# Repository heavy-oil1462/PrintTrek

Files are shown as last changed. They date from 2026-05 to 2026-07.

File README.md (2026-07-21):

# PrintTrek

**PrintTrek** is an open-source, highly engineered, and modular offroad adventure trailer designed to be manufactured using a custom CNC router (like the PrintNC) and basic hand tools.

The whole chassis is bolted together, not welded. That is the point: you do not need welding experience, a welder, or a shop to build one. If you can drill, bolt, and torque to a spec, you can assemble the frame at home with hand tools, and the result is a joint that does not carry the fatigue risk of a bad weld you cannot inspect.

Built to traverse rugged terrain and function as an ultimate basecamp, it is specifically designed to be the perfect companion for a mid-size pickup (like the Ford Ranger), matching its track width, wheel specs, and offroad capabilities.

## Project Goals

1. **Weld-Free Assembly:** Eliminate the barrier of entry and fatigue issues associated with welding. The entire frame is bolted together using through-bolts and heavy-duty, CNC-milled aluminum corner plates (the "double sandwich" method).
2. **Open Source & Maker-Friendly:** Provide complete, open-source CAD files and instructions so anyone with access to a CNC router (like a PrintNC) can mill the complex components themselves. Additionally, 3D printed drill guides will be provided for precise hole placement, and a simplified geometry version will be available for builders without CNC access.
3. **Extreme Durability:** Utilize hot-dip galvanized steel framing, 6082-T6 aluminum nodes, and strict galvanic corrosion protection to ensure the trailer survives decades of abuse in harsh environments.
4. **Safety & Separation of Systems:** Isolate electrical and network systems on the left side of the chassis, and the propane system entirely on the right side.
5. **Modularity:** Allow builders to customize the body panels (Dibond/plywood), electrical payload, and slide-out kitchen configuration without compromising the core structural integrity.

## Key Features

- **Tow-Vehicle Synchronization:** Matches the Ford Ranger's 6x139.7 bolt pattern and track width, allowing the use of shared spare wheels (e.g., 265/60R18 Falken Wildpeak A/T3W).
- **CNC-Optimized Design:** Heavily relies on flat-pack milled aluminum brackets, niches, and nodes that can be routed accurately at home.
- **Off-Grid Capabilities:**
  - 40L food-grade water tank centrally mounted with a 3mm aluminum skid plate.
  - Dedicated drawbar mount for a 6kg propane cylinder with built-in stone protection.
  - Recessed, milled niches for external water, gas, and power outlets.
  - Modular "Power Station" 12V box, 230V mains integration, and Teltonika 5G network integration.
- **Slide-Out Kitchen:** Accommodates a heavy-duty drawer (100-150kg slides) for a 12V compressor fridge (e.g., Dometic CFX), fed via an electrical-only energy chain. Propane stays on fixed pipes to external quick-connects for outdoor cooking.
- **ESPHome + Home Assistant Control:** An ESP32 running ESPHome (relays + sensors, MQTT) with Home Assistant as the UI — monitoring water level, battery voltage/current, and temperatures, and switching the pump, lights, and fridge directly. Battery protection (tiered load shedding), pump dry-run cutoff, and runtime watchdogs run locally on the ESP32, so the network can be down without risk. Includes a full software twin: the real firmware runs under QEMU in a container against your own broker (`docs/SIMULATION.md`).

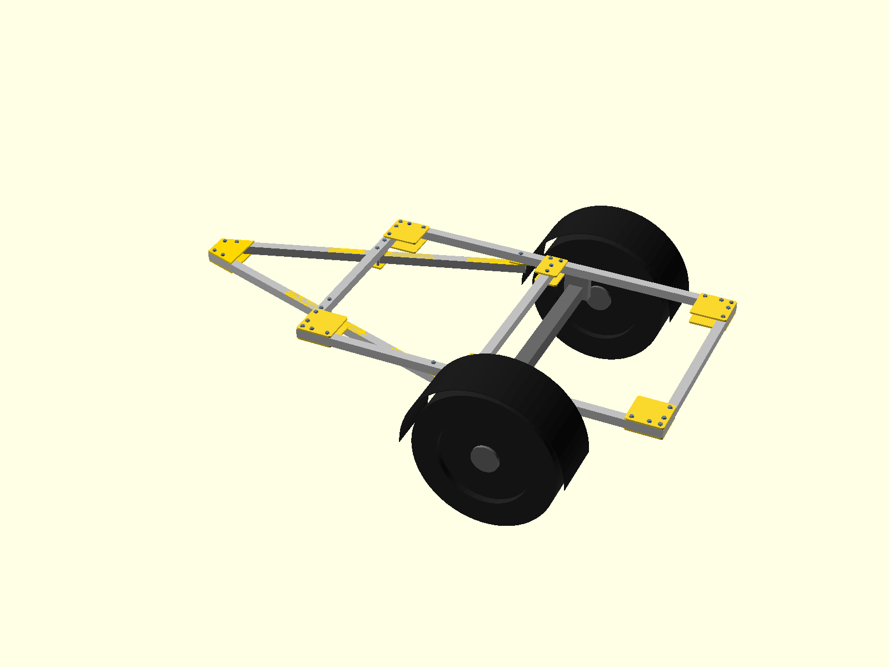
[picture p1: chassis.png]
Chassis — the load-bearing core


*The load-bearing core (what the project stands or falls on): 2000×1200 mm bolted VKR 50×50×3 frame with CNC-milled corner/T-plates, a **V-drawbar** of two straight square-cut arms in the SAME 50×50×3 profile — tied at the apex by a flat CNC plate sandwich (no welds, no miter cuts), sleeve-clamped at the front crossbeam (bolts beside the arm — no holes in it), through-bolted at the rail ends — and a braked torsion axle matching the Ford Ranger's 1560 mm track. Lateral towing loads go AXIAL through the triangle instead of bending a single beam (combined-case SF 3.0 vs 1.8). Sizing math lives in `scripts/beam_check.py` + `fea/`. Everything else (body, galley, systems) is ideation-stage layout on top of this chassis.*

## Structural Analysis

Hand-calcs (`python3 scripts/beam_check.py`) + CalculiX FEA, both validated against each other. Rebuild every derived artifact (FEA decks + solve + all renders + mass budget) on any machine with `scripts/regen_all.sh`, and gate commits with `scripts/verify_design.sh` (read-only: renders, deck drift, budget flags, FEA safety factors). FEA alone: `scripts/run_fea.sh` (needs `ccx`; renders need `pip install numpy matplotlib`). Materials: S355 steel for all VKR beams, 6082-T6 aluminum for all CNC-milled plates.

| | |
|---|---|
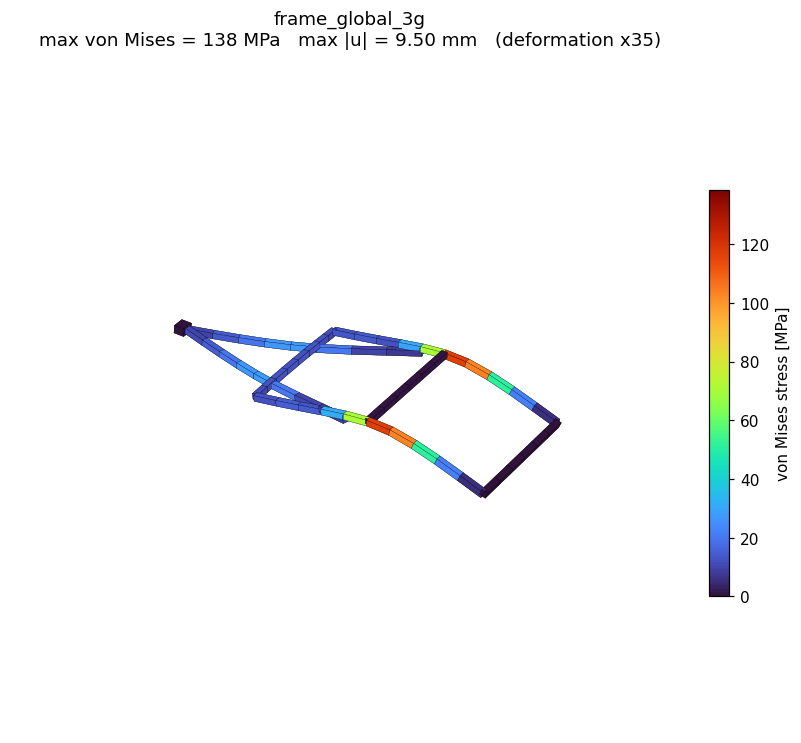
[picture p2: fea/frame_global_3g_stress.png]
Whole chassis, 3g
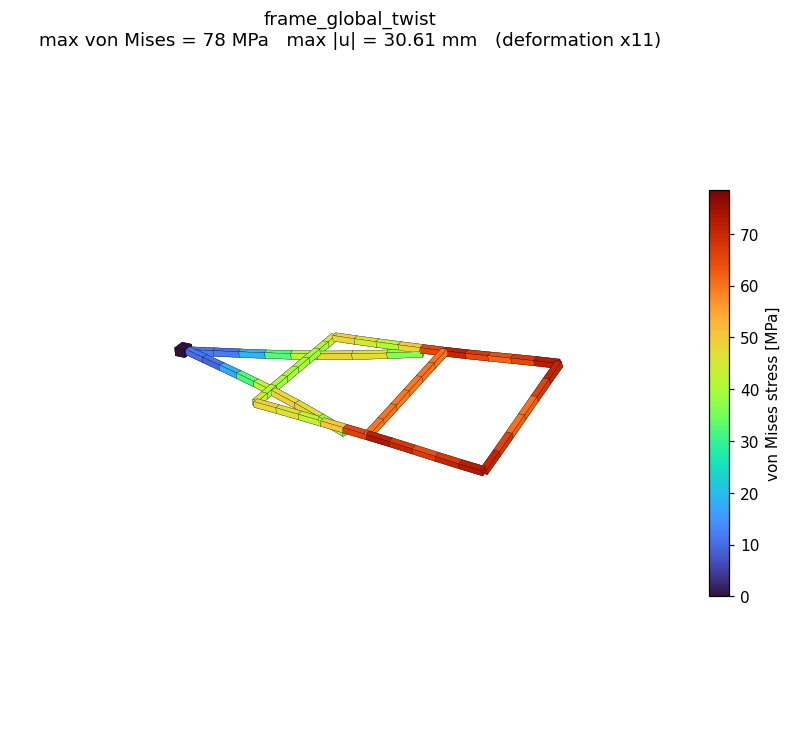
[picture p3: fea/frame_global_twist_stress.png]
Whole chassis, racking
|  |  |
| **Whole chassis, 3g deck load** — rails 130 / crossbeams 16 / V-arms 31 MPa, **SF ≥ 2.7 on every member** (bounding: full 400 kg at 3g); bolted laps appear as connectors (28 MPa — bolt preload/friction budget in `check_v_joints`) | **Whole chassis, diagonal racking** (one corner lifted 30 mm) — 74/70 MPa; the bolted ladder frame is torsionally soft, which is what you want off-road |
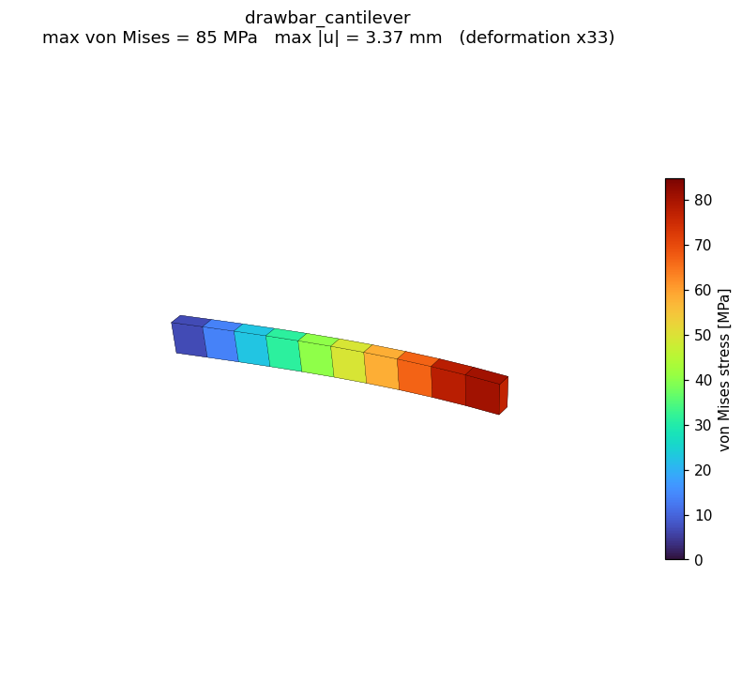
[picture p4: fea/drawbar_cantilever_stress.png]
Drawbar FEA
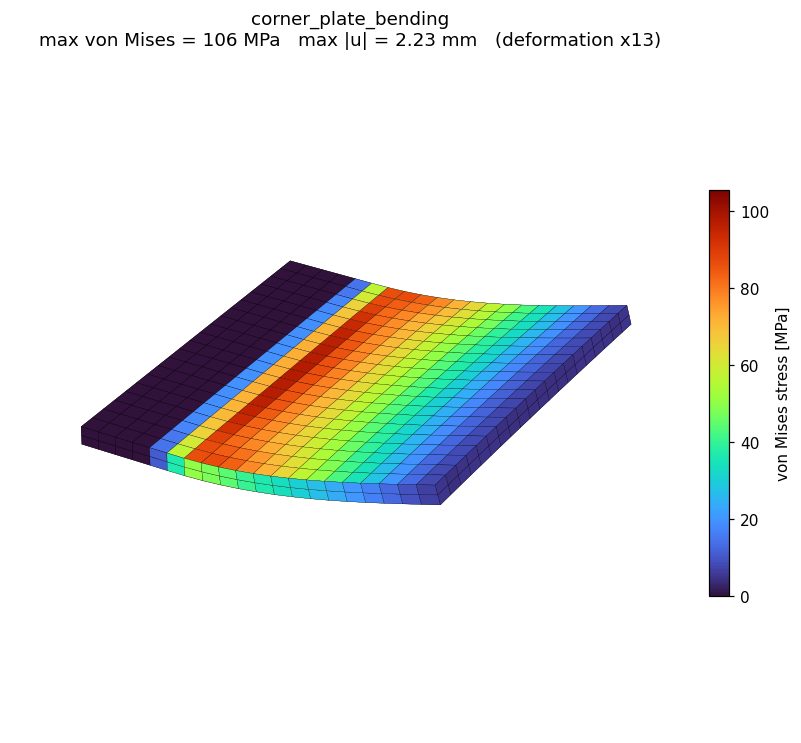
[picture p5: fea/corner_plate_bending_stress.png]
Corner plate FEA
|  |  |
| **Single-bar drawbar** (legacy variant, kept as solver validation): 85 MPa at the root, SF ≈ 4 — matches the hand calc | **Corner plate** (aluminum, prying bound): 106 MPa at the clamp line, SF ≈ 2.5 even with one plate taking the full couple |

The fatigue-governing detail of any bolted drawbar is a bolt hole at the peak-moment point (`check_joint_hole` / `check_v_joints` in `beam_check.py`), so the rule everywhere is **no holes where bending peaks**: at the front-crossbeam crossing the V-arms are CLAMPED — two bolts pass through the crossbeam *beside* the arm, through spacer sleeves, pulling a plate up under it — and through-bolted only at the rail ends and apex plates, where arm moment is ~zero. Every structural bolt runs at full preload on a crush sleeve, so service loads are carried by **friction grip** (SF ≥ 3.9, `check_v_joints`) — the bolts never work in shear and the holes stay clamped shut. Per-member tables and model notes in [`fea/README.md`](fea/README.md).

## Design Snapshots (ideation-stage layout)

| | |
|---|---|
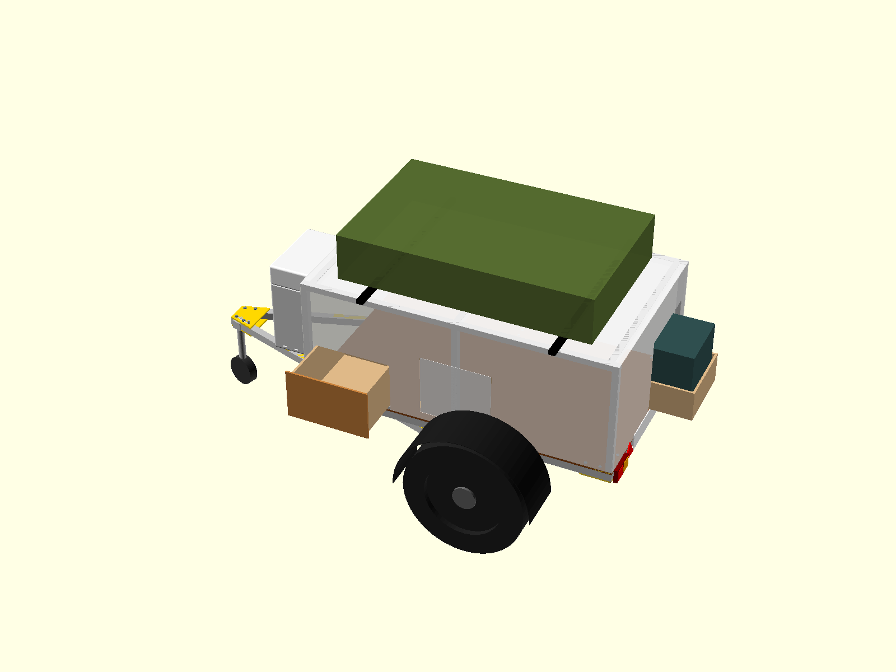
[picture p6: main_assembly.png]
Main assembly
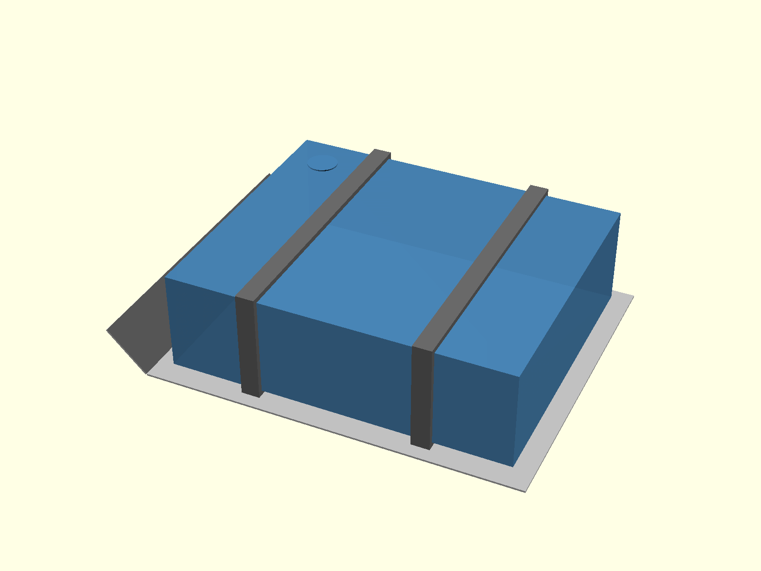
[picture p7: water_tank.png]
Water tank + skid plate
|  |  |
| **Full assembly concept** — kitchen side-drawer front left, storage cabinet mid left, electrical bay mid right, fridge drawer out the rear right | **Low-profile 40 L water tank** — 160 mm deep so the 3 mm skid plate sits level with the axle tube (~405 mm clearance); mounting under review, currently not in the assembly |

The body/galley layout is still being iterated and does not drive the structure. Renders are generated headlessly with `scripts/render_scad.sh cad/<model>.scad <output>.png` (chassis-only: add `-D show_cabin=false -D show_equipment=false`).

## Control System (ESPHome + Home Assistant)

The trailer is controlled by an ESP32 running [ESPHome](https://esphome.io) with Home Assistant as the UI. Everything below needs the toolchain on PATH — `pip install -r requirements.txt` (plus the mosquitto system package) or the pinned dev shell (`nix develop`), whichever you prefer:

```bash
python3 tools/stack.py init && python3 tools/stack.py up   # dev stack: mosquitto + HA
python3 tools/mock_device.py --discovery                   # software twin, no hardware
esphome run esphome/example-trailer.yaml                   # real hardware (copy + edit first)
```

Or run the REAL firmware without hardware — an esp32 build under Espressif QEMU in a container, against your own broker and HA, with a web panel to inject sensor values (`docs/SIMULATION.md`):

```bash
python3 tools/sim_container.py build
python3 tools/sim_container.py run --broker <mqtt-host> --username u --password p
```

The node is live on the network by default (direct switch control from HA); a duty-cycled storage mode with retained setpoints is one switch away. Safety logic — tiered battery load shedding, pump dry-run cutoff, runtime watchdogs — runs locally on the ESP32 regardless of connectivity. The MQTT contract is in [`docs/PROTOCOL.md`](docs/PROTOCOL.md); adopt/extend via composable packages per [`docs/EXTENDING.md`](docs/EXTENDING.md); controller wiring in [`docs/HARDWARE.md`](docs/HARDWARE.md).

## Toolchain and CI

Nix is optional everywhere. The software gate needs python3 plus esphome, yamllint and the esphome_skills package (`pip install -r requirements.txt` or `nix develop`); the CAD pipeline needs a 2024+ OpenSCAD dev snapshot, resolved as `$OPENSCAD`, then `openscad` on PATH, then nix; CalculiX resolves the same way (`$CCX`, PATH, nix). The pre-commit gate is `scripts/verify_design.sh`, and CI (`.github/workflows/`) runs exactly the same gates from pip with no nix: `validate.yml` (configs + MQTT protocol test) on every change, `design.yml` (CAD renders, FEA drift and safety factors, mass budget) on design-side paths, `firmware.yml` (full C++ build of both node configs) on firmware paths.

## Repository Structure

- `/cad`: Contains all the 3D models and manufacturing files (e.g., OpenSCAD, STEP, or STL files) for the corner plates, niches, and chassis geometry.
- `/concepts`: Markdown files and diagrams detailing sub-systems (like electrical routing, propane layout, and water flow).
- `/esphome`: The trailer control firmware — a composable ESPHome base + packages (sensors, actuators, load shedding); see `docs/EXTENDING.md`.
- `/homeassistant`: Home Assistant package (derived sensors, alerts), alert blueprint, and an example dashboard.
- `/server`: Dev/test stack (mosquitto + Home Assistant via docker compose). The production stack will run nix-managed on the trailer's Raspberry Pi.
- `/sim` and `/tools`: The firmware simulator (real esp32 build under QEMU + web control panel), mock device, protocol test, and the validation gate (`tools/validate.py`).
- `/docs`: Control-system contracts — `PROTOCOL.md`, `EXTENDING.md`, `HARDWARE.md`, `SIMULATION.md`.
- `/scripts`: Helper tools — `calculate_tubes.py` (steel cut list from the CAD files) and `calculate_mass.py` (weight, center of gravity, and tongue-load budget).
- `MATERIALS.md`: A comprehensive Bill of Materials (BOM) detailing the steel, aluminum, fasteners, and specific off-the-shelf components required.
- `SPECS.md`: The core technical specifications and overarching design decisions.
- `TODO.md`: The phased checklist of design, purchasing, and construction tasks.

## How to Contribute or Build Your Own

Currently, the project is in the **Concept & CAD Design phase**. 

If you are interested in building your own PrintTrek, or want to contribute to the CAD models, electrical schematics, or documentation, feel free to fork this repository, open an issue, or submit a pull request!

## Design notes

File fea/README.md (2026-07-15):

# FEA — CalculiX models

Finite-element checks for cases where the hand-calcs in
`scripts/beam_check.py` aren't enough (joint details, plate bending,
combined load paths). Solver: **CalculiX (ccx)**, open source.

## Run it (any host)

```bash
scripts/regen_all.sh        # EVERYTHING: decks + solve + all PNGs + mass budget
scripts/verify_design.sh    # read-only checks incl. FEA SF >= 1.5 (pre-commit)
scripts/run_fea.sh          # just this: solves every fea/*.inp + renders PNGs
```

The script finds `ccx` via `$CCX` → PATH → nix-build fallback
(Debian/Ubuntu: `apt install calculix-ccx`). Renders need
`python3` with numpy + matplotlib (`pip install numpy matplotlib`);
without them the solve still runs and the script prints a hint.
Single deck: `scripts/run_ccx.sh fea/<deck>` (no `.inp` extension).
Render manually: `python3 scripts/plot_fea.py fea/*.frd`.

## Materials (configured per part, units mm/N/MPa)

| Material | Used for | E [MPa] | ν | Yield [MPa] |
|---|---|---|---|---|
| **S355J2H steel** (`*MATERIAL, NAME=S355`) | VKR beams: frame, drawbar, crossbeams | 210 000 | 0.30 | 355 |
| **6082-T6 aluminum** (`*MATERIAL, NAME=AL6082T6`) | CNC-milled plates: corner, T, spacer, cradle | 70 000 | 0.33 | 260 |

## Conventions
- Beam models use `B32R` elements (`SECTION=BOX` requires the reduced-
  integration type in ccx); solid plate models use `C3D8I` (good in bending).
- Every deck header states the load case and the expected hand-calc result —
  a model that can't be sanity-checked is worse than no model.
- Only `.inp` decks and `_stress.png` renders are versioned; `.dat`/`.frd`
  solver output is disposable (gitignored).

## Models

### drawbar_cantilever.inp — steel, VALIDATED ✔
Single-bar drawbar LC1 (legacy variant — kept as the beam-model solver
validation): VKR 100x50x4 standing, 1090 mm cantilever, 3g × 80 kg = 2354 N
tip load.

| Quantity | Hand calc | ccx |
|---|---|---|
| Tip deflection | 3.36 mm | 3.36 mm |
| Root bending stress | 89.0 MPa | 84.7 MPa* |

Drawbar stress

### corner_plate_bending.inp — aluminum, VALIDATED ✔
Corner plate prying bound: 200×200×10 mm 6082-T6 plate, clamped strip over
the tube face, 2.5 kN transverse at the free edge (≈ drawbar-lap couple).
Conservative: one plate takes what the top+bottom sandwich pair shares.

| Quantity | Hand calc | ccx |
|---|---|---|
| Edge deflection | 2.15 mm (plate-stiffened) | 2.23 mm |
| Clamp-line stress | 113 MPa | 105.5 MPa* |

SF vs 6082-T6 yield (260 MPa): **~2.5** even in this bounding case.

Corner plate stress

\* ccx reports stress at integration points slightly inside the extreme
fiber / clamp line — reading a few % below the hand-calc envelope is
expected; use the hand calc as the conservative number.

### frame_global_3g.inp + frame_global_twist.inp — WHOLE CHASSIS
The entire load-bearing structure in one beam model: rails, three
crossbeams (front, mid at x 950-1000, rear — no beam over the axle, the
bolted axle tube ties the rails there), and the **V-drawbar** (default,
`v_drawbar` in `cad/design_params.scad`): two straight 50×50×3 arms
35 mm below the frame plane, sharing the apex node (= the apex-plate
sandwich), a stiff APEX connector out to the coupling, and short
vertical VJOINT connectors for the bolted laps at the front-crossbeam
crossings and the rail ends. The legacy single-bar variant remains
generated by `v_drawbar=false`. Vertical supports sit on the RAILS at
the axle brackets (x≈1100). Generated parametrically:
`python3 scripts/gen_frame_fea.py`.

**LC 3g vertical** (400 kg deck × 3g, supported at coupling + axle
brackets) — max von Mises per member group:

| Member group | max vM | SF vs 355 |
|---|---|---|
| Side rails | 130 MPa | 2.7 |
| Crossbeams | 16 MPa | 22 |
| V arms (DRAWBAR) | 31 MPa | 11* |
| Lap connectors (VJOINT) | 28 MPa | 13 — bolt-level check: `check_v_joints` |

\* the isolated 3g-tongue case (164 MPa/arm, SF 2.2, `check_v_drawbar`)
remains the arms' governing envelope — dynamic pitching loads the
tongue independently of the deck. The rails govern the frame in this
bounding case (full 400 kg payload at 3g), same as before: the V
actually RELAXES the front crossbeam (27 → 16 MPa) because the coupling
reaction enters at two crossing points instead of mid-span. The two
OPTIONAL floor crossbars (x=500/1500, `floor_crossbars` toggle, OFF by
default) change frame-member stresses by ~nothing — verified here —
their job is the formply floor span, lashing points, and the water-tank
hanger, not the frame.

**LC diagonal racking** (three corners held, fourth lifted 30 mm): rails
74 / crossbeams 70 / V arms 56 MPa; the lap connectors read 60 MPa
(load-path indicators for the bolted joints). The open ladder frame is
torsionally soft — good off-road, and stresses stay low. (A "one
wheel up" case with a ball coupling is a near-rigid roll of the whole
trailer — verified zero stress — because the ball transmits no roll
moment.)

Global 3g
Global racking

**Joint modeling honesty:** member intersections are rigid shared nodes
and the laps are stiff links — **bolts are not modeled discretely** (no
preload, no contact, no friction in these decks). That idealization is
fair as long as every joint stays in friction grip, which is exactly
what `check_v_joints` in `scripts/beam_check.py` verifies (M12 8.8 at
full 47 kN preload, μ=0.2 slip capacity vs joint demands, SF ≥ 3.9).
Bolt shear/bearing and net-section fatigue live there too; a true
preload+contact model of one bolted joint is still open work.

## Next candidates for FEA (when the design firms up)
- **Drawbar cradle joint** (`cad/drawbar_cradle.scad`): preload+contact
  model of cradle + beam + crossbeam confirming the no-hole-in-flange
  concept — see `check_joint_hole` in `scripts/beam_check.py`.
- Local wall bending of the 4 mm RHS around the crush sleeves under the
  lateral couple.
- Semi-rigid joint stiffness in the global model (springs calibrated from
  a single-joint contact model) instead of rigid shared nodes.

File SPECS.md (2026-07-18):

# Technical Specifications & Design Decisions

## Overall Goals
- **Tow Vehicle:** Ford Ranger
- **Track Width and Bolt Pattern:** Matched exactly to the tow vehicle (6x139.7). Tire size: 265/60R18 Falken Wildpeak A/T3W on Ford original rims. The Ranger's underslung spare serves both car and trailer — no spare is carried on the trailer.
- **Manufacturing Technique:** Custom-built CNC router (PrintNC) is utilized maximally for precision, corner joints, brackets, niches, and modular panels. Additionally, 3D printed guides will be used to ensure precise drilling of holes in the steel beams. A simplified, non-CNC version with cruder geometry will also be provided for builders without access to CNC routing.

## 1. Chassis & Mechanics
- **Frame Structure:** Square steel (VKR 50x50x3 or 60x40x3 mm), frame 2000 x **1200 mm**. Crossbeams at ~500 mm spacing (x = 0 / 500 / 975 / 1500 / 2000): the mid beam ties the rails ahead of the axle (and takes the drawbar lap in the legacy single-bar variant); the two floor crossbars are **OPTIONAL** (single toggle `floor_crossbars` in `cad/design_params.scad` — ONE file read by the CAD assembly, the mass budget, and the FEA generator alike; per-run overrides via UPPERCASE env vars, e.g. `FLOOR_CROSSBARS=true scripts/regen_all.sh`) and exist for the **floor**, not the frame — they halve the formply's unsupported span under cargo point loads, provide lashing/body mounts, and the rear one is the water-tank hanger. Each end bolts to the rail through the same **top+bottom T-plate sandwich** as the mid crossbeam (same CNC part, same joint everywhere in the frame — 4 plates per bar). Cost of the pair: +22 kg incl. plates; the toggle is **OFF by default** in all three places. (FEA: frame-member stresses are unchanged by them — rails are supported by the wheels and coupling, not by crossbars.) The frame was narrowed from 1400 mm because matching the Ranger's 1560 mm track is otherwise geometrically impossible: with 265 mm tires, tire-to-body clearance is (1560-265)/2 - 600 = **47.5 mm** at 1200 mm width, but negative at 1400 mm. No full welding to prevent fatigue cracks; the frame is bolted together with through-bolts (M12 in 8.8/10.9 grade — one bolt size frame-wide, 2 per plate arm on the tube centerline).
- **Bolted Joints (critical):** Every through-bolt runs through an **internal steel crush sleeve** (precision tube, 20x3 mm for M12) so the bolt can be torqued to full preload without collapsing the 3 mm RHS walls. Lock nuts and hardened washers throughout. **Re-torque all structural bolts after the first ~500 km, then annually.**
- **Drawbar (DECIDED 2026-07-15): V-drawbar (A-frame)** of two straight, square-cut **VKR 50x50x3** arms — the same profile as the rest of the frame, so ONE tube size builds the whole trailer. The arms run from under the side rails (rear ends at x=800 — the V is kept this narrow so the crossing clamp bolts clear the 200×200 corner plates) through the front crossbeam to the coupling apex; all the V geometry lives in one flat CNC part, the **apex plate** (`cad/v_apex_plate.scad`, 10 mm 6082-T6, top+bottom sandwich over both arm ends) — **no welds, no miter cuts**, and the tips stop with a deliberate ~40 mm gap (`v_tip_gap`) so cut tolerance never lets the tubes press on each other. Why it beats the single bar (`check_v_drawbar` in `scripts/beam_check.py`): vertical 3g tongue splits over two arms (164 MPa/arm, SF 2.2); **lateral loads resolve AXIALLY through the triangle** (6 MPa, vs 135 MPa weak-axis bending + a lap couple in the single bar); the governing combined case (2g vertical + 0.3g lateral) gives **SF 3.0 vs 1.8** for the single bar — and the pair is ~5 kg lighter. Arm buckling SF ~100. Attachment: **front-crossbeam crossing = SLEEVE-CLAMP** — two M12 pass through the crossbeam 45 mm each side of the arm, down through 60 mm spacer sleeves into a 10 mm clamp plate under the arm, squeezing it against the wedge plate/crossbeam. **Zero holes in the arm** at its peak-moment point (the fatigue rule), and nothing lands on a beam edge — U-bolts were tried and rejected (at the ~70° skew their legs hit the crossbeam's edges). **Rail ends = ONE M12 through-bolt** each (the shallow overlap only has edge distance for one; arm moment ~zero there); **apex plates = 2x M12 per arm**; crush sleeves everywhere. The coupling-head mounting at the apex is an open design point (type-approved head required). The legacy **single central VKR 100x50x4** remains fully modeled (CAD, mass, FEA) behind `v_drawbar=false` in `cad/design_params.scad`. There is still **no separate crossbeam over the axle**: the bolted axle tube ties the rails via its brackets; the mid crossbeam is now purely a rail tie.
- **Drawbar joint rule — NO HOLES AT THE PEAK-MOMENT POINT.** The governing detail of any bolted drawbar is never the beam, it's a bolt hole through a tension flange where bending peaks (net section −17%, kt ≈ 2.5, fatigue margin collapses — `check_joint_hole`). In the **V-drawbar (default)** this is why the front-crossbeam crossing is the **beside-the-arm sleeve-clamp** and through-bolts appear only at the rail ends and apex plates where arm moment is ~zero (`check_v_joints`: with holes at the crossing the 2g fatigue range fails, 139 MPa vs category 90; clamped it passes with 1.45× margin). For the **legacy single bar** the same rule produced the front-crossbeam clamp — vertical bolts *beside* the beam, horizontal M12 through the webs at the **neutral axis**. Three interchangeable single-bar implementations, same structural concept:
  1. **Angle-bracket pair** (was the decided single-bar joint): 2x hot-rolled **L80x80x8** S355, 120 mm long, straight cuts only, galvanized with the frame (`cad/drawbar_angle_joint.scad`). Leg-bending SF ≈ 3.4 with the pair coupled by the through-bolts (`check_angle_joint` in `beam_check.py`); 6 mm legs drop to SF 1.9 — use 8 mm. The 10 mm spacer plate stays.
  2. **CNC-milled 6082-T6 cradle** (`cad/drawbar_cradle.scad`): one-piece channel + wings, integrated spacer web — the premium/CNC variant.
  3. **Square U-bolts** (fyrkantbygel M12 for 50 mm profile) + top plate: fully off-the-shelf trailer hardware; add a saddle strip so the U-bend doesn't dent the tube corners. (Note: U-bolts do NOT work for the V-drawbar's crossings — at the ~70° skew their legs land on the crossbeam's edges — which is why the V uses the sleeve-clamp instead.) The coupling itself must be a type-approved unit with a documented rating.
- **Corner Reinforcements:** "Double sandwich" with heavy-duty, CNC-milled 8-10 mm aluminum plates (6082-T6) on the top and bottom of each 90-degree corner.
- **Surface Treatment:** The steel frame is hot-dip galvanized after drilling. Holes are drilled 13 mm (M12) and **reamed clean after galvanizing** — hot-dip adds ~100 µm of zinc per surface.
- **Corrosion Protection:** Duralac (anodic paste) on all steel–aluminum interfaces; optionally a thin *rigid* isolator sheet (0.5-1 mm G10/FR4). **No rubber or vinyl inside structural joints** — elastomers creep under sustained compression and destroy bolt preload, which is the exact loosening/fatigue failure mode the bolted design must avoid. Note that galvanized steel against aluminum is a relatively benign pairing (zinc is anodic to aluminum), so paste + galvanizing is sufficient protection.
- **Suspension:** Torsion (rubber) axles have limited travel (~70 mm) and no damping — on washboard/corrugated roads they overheat and pound the payload. Specify **shock absorbers (damper kit)** with the torsion axle as a minimum; evaluate axle-less trailing-arm setups (e.g., Timbren) if serious off-road use is intended.

## 2. Electrical System & Electronics (LEFT Side)
- **Placement (sides in TRAVEL direction):** All electrical is concentrated on the **right side**: the electrical bay (removable power-station box, IP65 cabinet, el-niche with router panel) sits mid-right, directly **ahead of the fridge drawer** (rear right). The 230V CEE inlet sits on the front wall's right half, mounted high — a short, clean feed down into the right-side bay. **NOTE:** the old strict gas-left/electric-right separation principle is *parked* while the interior layout settles (decision 2026-07-08: layout first, then refine gas routing/placement around it).
- **Cable Routing:** Cables in corrugated conduits inside the steel frame. The conduits exit the steel before the corners and are routed in a soft curve protected within the tunnel between the corner plates.
- **Grounding:** Single-Point Grounding (Star grounding). The steel frame is equipotentially bonded with a 6 mm² yellow/green cable to a grounding terminal in an IP65 electrical cabinet.
- **230V Network:** Blue CEE inlet -> Fuse box (RCD + 10A/13A circuit breakers) -> Outlets (fridge, Noco charger, IP66 external).
- **12V & Battery Module:** Detachable Power Station box with a **200 Ah LiFePO4** bank, DC-DC MPPT charger, Noco charger, and Anderson connectors. Charged from the car's 13-pin socket while driving and from a **200 W solar panel** on the roof rack (MC4 via the external solar input).
- **Energy Budget (12V):** Maintained in `scripts/calculate_energy.py` — edit the load table there and re-run as components are chosen. Current estimates: ~64 Ah/day total (compressor fridge ~34, router/RPi/lights/pump ~30). Autonomy with 200 Ah + 200 W solar: **~32 days parked in summer sun, ~5 days in shade/shoulder season, ~3.4 days overcast**; one day's consumption is recovered by ~2 h of driving (30 A DC-DC). The comparison in the script also shows why the gas absorption fridge was rejected: without solar even *it* is battery-limited to ~3 days by the base loads, so solar is required either way — and a compressor fridge with solar then beats gas on every axis (works off-level, no flame under the roof tent, no flue, slide-out compatible).
- **Network:** Teltonika 5G industrial router, coaxial LMR-200/400 to Poynting puck antenna. Waterproof N-connectors in a CNC-milled, recessed panel.
- **Monitoring & Control:** An ESP32 running ESPHome (in the electrical bay) switches the pump, exterior lights, and fridge relay and reads battery voltage/current (INA226 + shunt), tank level, interior climate, and fridge temperature over MQTT into **Home Assistant** — direct control from HA, with the safety logic local on the ESP32 (tiered battery load shedding, pump dry-run cutoff, runtime watchdogs; `docs/PROTOCOL.md`). The on-trailer server is a Raspberry Pi; the dev stack lives in `server/`, the production Pi will run a nix-managed HA/Grafana/Loki/Prometheus stack (separate config, not in this repo yet).

## 3. Propane System (RIGHT Side)
- **Separation:** All propane on the right side for complete isolation from the electrical system.
- **Bottle housing:** 6 kg (P6/PK6) in a **caravan-style gas locker box** on the drawbar, flush against the front wall (`cad/gas_box.scad`). Lockable and weatherproof (stone protection all around, not just a front guard), with **low-level vent slots per EN 1949** (propane sinks) and the regulator/hose inside; the fixed pipe exits a floor gland to the right-side rail. Available off the shelf (poly drawbar boxes, Fiamma/Thule class) or CNC-folded in aluminum tread plate. Mounted on bearers **clamped** around the drawbar — the forward beam carries near-peak bending moment, so no holes in it. (The open CNC cradle + stone guard remains as the budget alternative, `cad/gas_bottle_mount.scad`.)
- **Routing:** Fixed, clamped copper or steel pipes under the right frame. Bulkhead fittings at consumers.
- **External Outlets:** Two fixed gas quick connects (GOK/Truma) in CNC-milled protective niches on the **right wall**: one **front-right** (short hose around the front to the slide-out kitchen counter on the front left) and one **rear-right** (griddle/outdoor kitchen at the tail). Mounted low-ish — propane is heavier than air, so the connects stay below the 230V inlet and away from any opening into the cabin — but above wheel-spray height.

## 4. Water System & Interior
- **Water Tank (mounting UNDER REVIEW):** 40-liter **low-profile** tank (550x450x160, food-grade with baffles), modeled in `cad/water_tank.scad` but currently removed from the main assembly — the underslung mounting is being reworked. Candidate spot: **behind the axle, centered** (x≈1400) — freed up now that no spare wheel is carried; there is no drawbar under the floor there (the beam ends at x=1020) and it balances the gas box up front. Caveat: with water behind the axle, the tongue load *rises* as the tank drains (see the dry-tank line in `calculate_mass.py`). Shallow on purpose: at 160 mm depth the skid plate sits ~405 mm above ground, level with the axle tube, instead of being the trailer's lowest point. Protected by a 3 mm aluminum tread skid plate with a beveled leading edge. Mass is kept as a placeholder in the tongue budget.
- **Water Components:** External lockable filler (in Dibond wall), 12V pressure-controlled galley pump (Seaflo/Shurflo), central drain valve.
- **Body:** Floor in 12-15 mm vehicle plywood (formply). Sides in 3-4 mm Dibond on steel/aluminum framework.
- **Galley & Bay Layout (sides in TRAVEL direction, `cad/kitchen_drawer.scad`):**
  - **LEFT, front → rear:** kitchen side-drawer, then storage cabinet.
    1. **Kitchen side-drawer (front left):** 520 x 680 mm drawer on 100-150 kg lock-in/out slides, pulling out *sideways* through an opening in the left wall — worktop over the rear half, open bins in front. Structural slides only in CAD; taps/stove are loose equipment.
    2. **Storage cabinet (mid left):** Fixed plywood cabinet (650 x 450 x 550) for utensils/dry goods, exterior door in the left wall (x 780-1240).
  - **RIGHT, front → rear:** electrical bay, then fridge drawer.
    3. **Electrical bay (mid right):** Mirrored cabinet housing the removable **power-station box** and distribution; the el-niche (router/connection panel) sits in its front bay, and the exterior door in the right wall (x 780-1240) lets the box lift out. Directly ahead of the fridge = short, fixed 12V run to the trailer's biggest consumer.
    4. **Fridge drawer (rear right):** A fridge-sized tray (640 x 450, low sides) on slides, pulling out *rearward* through a **fridge-sized hatch on the rear right** (500 x 520 mm, sill-free at floor level) — the rest of the rear wall, including the whole rear left, is solid. Holds the **12V compressor fridge** (e.g., Dometic CFX or Engel). A compressor fridge works off-level, has no flame/flue, and integrates with the ESPHome-controlled fridge relay — a 3-way absorption fridge was rejected: it must be near-level to run, needs a fixed flue and ventilation on gas (EN 1949), and an open-flame appliance on a moving drawer would be very hard to get approved.

  **The energy chains to both drawers carry electrical only** — propane stays on fixed pipes to external quick-connects. CNC-milled ventilation grille in the trailer side for the fridge compressor. Note: **no spare wheel is carried on the trailer** — the wheel spec matches the Ford Ranger exactly (6x139.7, 265/60R18 on original rims), so the car's underslung spare serves both. That is the shared-spare design goal paying off, and it keeps the tailgate free for the fridge drawer.

## 5. Road Legal & Registration (Sweden)
- **Approval:** An amateur-built trailer requires *registreringsbesiktning* (individual approval) before road use. Contact the inspection body (Besikta/Opus/Dekra) early — their requirements drive design decisions.
- **Weight class (DECIDED):** The trailer will be **braked** (overrun/auflauf brakes — braked torsion axles with 6x139.7 hubs exist from Knott/AL-KO). This permits registering a total weight above 750 kg, giving real payload margin — the current curb-weight estimate (~585 kg) leaves almost nothing under an unbraked 750 kg rating. The running weight and tongue-load budget is maintained in `scripts/calculate_mass.py`.
- **Tongue load:** Target roughly 5-10% of total weight; up to ~12% is acceptable (and stability-positive) as long as it stays within the coupling's S-value and the Ford Ranger towbar's rated ball load. `calculate_mass.py` reports both the water-full and water-empty states — with the tank behind the axle, the tongue rises as water is consumed.
- **Lighting & marking:** Full lighting per UNECE R48 (tail/brake/indicators, number-plate lamp, rear fog, reversing light where required), triangular rear reflectors (trailer-specific), side/front reflectors. E-marked components only.
- **Mudguards/fenders:** Required — not yet in the CAD model.
- **Coupling & safety:** Type-approved coupling head matched to the Ranger's ball height, plus breakaway cable (or safety chain for unbraked class) and jockey wheel.

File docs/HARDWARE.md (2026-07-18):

# PrintTrek controller hardware guide

Reference build for the stock packages. Everything is swappable — see
EXTENDING.md — but this exact combination is what `example-trailer.yaml`
compiles for. The trailer-wide electrical design (bank, solar, DC-DC,
distribution, grounding) lives in SPECS.md section 2; this file covers only
the ESP32 controller and its peripherals.

## Bill of materials

| Qty | Part | Notes | ~Cost |
|----:|---|---|---:|
| 1 | ESP32 DevKit (esp32dev, WROOM-32) | lives in the electrical bay (IP65 cabinet) | 6 EUR |
| 1 | INA226 breakout | battery monitor, I2C | 4 EUR |
| 1 | 50 A / 75 mV shunt | in the battery main negative | 8 EUR |
| 1 | SHT31 breakout (I2C) | interior temp/RH | 5 EUR |
| 1 | DS18B20 probe (waterproof) | fridge compartment | 3 EUR |
| 1 | Resistive tank level sender (or capacitive strip with 0-3 V out) | 40 L tank | 15 EUR |
| 1 | Buck converter 12 V -> 5 V (>= 1 A, low quiescent) | powers the ESP32 | 5 EUR |
| 3 | Automotive relay or logic-level N-MOSFET module (IRLZ44N class) | pump, lights, fridge | 6 EUR |
| — | 4.7 kOhm resistor (1-wire pull-up), divider resistors for the sender, wire, glands | | 5 EUR |

The pump, lights, fridge, battery bank, solar and DC-DC hardware are in the
main BOM (MATERIALS.md) — the controller just switches and measures them.

## Default pin map (all overridable via substitutions)

| Function | GPIO | Substitution | Constraint |
|---|---|---|---|
| I2C SDA / SCL | 21 / 22 | `i2c_sda` / `i2c_scl` | INA226 + SHT31 share the bus |
| Water level ADC | 34 | `water_adc_pin` | **ADC1 only** (32-39): ADC2 is unusable with WiFi. 34/35 are input-only. |
| Fridge DS18B20 (1-wire) | 4 | `fridge_onewire_pin` | 4.7 kOhm pull-up to 3.3 V |
| Fridge relay | 25 | `fridge_pin` | |
| Lights relay | 26 | `lights_pin` | |
| Pump relay | 27 | `pump_pin` | |

Avoid strapping pins (0, 2, 12, 15) for outputs that must not glitch at
boot — a boot glitch on the pump relay pressurizes the system unasked.

## Wiring

```
   12V bank (+) ──┬──────────► relay ──► fridge (12V compressor)
                  ├──────────► relay ──► pump
                  ├──────────► relay ──► exterior lights
                  └──► buck 12->5V ──► ESP32 5V/GND
   12V bank (-) ──[ 50A/75mV shunt ]── chassis loads return
                        │
                   INA226 (I2C): shunt sense + bus voltage tap to bank (+)

   tank sender ── divider from 3.3V ──► GPIO34
   DS18B20 (fridge box) ── data ► GPIO4, 4.7k pull-up to 3.3V
   SHT31 + INA226 ── I2C ► GPIO21/22
```

The INA226 measures NET bank current: positive while the solar MPPT or
DC-DC charges, negative while the fridge/pump/lights discharge. Put ALL
load/charge return paths through the shunt or the reading lies.

## Tank sender calibration

1. Flash, open logs (USB or OTA — the radio is always on by default).
2. Tank empty -> note "Water Level Raw Voltage" -> `water_raw_empty_v`.
3. Fill the tank brim full -> note voltage -> `water_raw_full_v`.
4. Set both substitutions in your node config, re-flash. Resistive senders
   step in ~10 % increments; treat the gauge as coarse.

## Power draw

The controller itself is a rounding error in the trailer's budget
(`scripts/calculate_energy.py`): ESP32 with WiFi on ~0.6 W, sensors ~0.1 W.
That is why "Radio Always On" is the default — the 200 Ah bank spends more
on the fridge in 10 minutes than the radio costs per day. Storage mode
(duty-cycled radio, docs/PROTOCOL.md) exists for winter storage where every
self-discharge amp-hour counts.

## Placement notes

- Controller in the electrical bay (mid right), on the 12 V distribution —
  short runs to the fridge drawer's energy chain and the pump.
- The SHT31 wants airflow, away from the fridge compressor's warm exhaust.
- Conformal-coat the tank sender connections; glands facing down.
- The DS18B20 lead runs inside the fridge drawer's energy chain with the
  12 V supply.

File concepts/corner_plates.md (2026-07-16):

# Concept: Corner Reinforcements ("Double Sandwich")

**Purpose:** Join the corners of the steel frame in an extremely strong and vibration-resistant way without full welding, preventing crack formation during off-road driving and facilitating hot-dip galvanizing.

## Design Parameters (For PrintNC CAD)
- **Material:** 6082-T6 Aluminum (Thickness: 8-10 mm).
- **Bolt Pattern:** 2x M12 (8.8/10.9) per plate arm on the tube centerline, spread wide (80/170 mm from the plate corner). Superseded the original 3x M10 zig-zag: the joints are friction-grip and never capacity-limited, but the zig-zag's ±12 mm offset left e2 = 1.18·d0 on the 50 mm face — at the EN 1993-1-8 floor. Centered M12 gives e2 = 1.9·d0, half the holes, and one bolt standard frame-wide. (Two holes 90 mm apart don't create the "perforation line" the zig-zag guarded against; net section per cross-section plane is one hole either way.)
- **Crush Sleeves:** Every through-bolt gets an internal steel sleeve (precision tube, 20x3 mm for M12) cut to the inner width of the VKR profile. Without sleeves the 3 mm tube walls collapse before the bolt reaches proper preload, and an under-torqued friction joint loosens under off-road vibration.
- **Routing/Bracing:** In addition to the 90-degree profile, integrate mounting points in the plates to secure the flexible conduits in the "cable tunnel" between the upper and lower aluminum plates.
- **Tolerances:** Holes drilled 13 mm (M12) and reamed after hot-dip galvanizing (~100 µm zinc per surface). Interface: Duralac paste, optionally a thin *rigid* G10/FR4 isolator sheet. No rubber/vinyl film in the joint — elastomers creep under clamping pressure and the bolt preload decays.

## CAD Iteration
1. Model the VKR steel corner and identify distances and potential collisions for bolts (don't forget washers).
2. Create negative space (the tunnel) where pipes and flexible conduits are allowed to exit the steel profile before the 90-degree junction, traveling protected between the plates. Especially important for the sensitive LMR coaxial cable to the 5G antenna which requires a soft bending radius.
3. FEA-simulate the corner (static load and torsional force) if possible, to save weight in the aluminum plates (e.g., by milling pockets where material is redundant).

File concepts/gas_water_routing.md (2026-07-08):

# Concept: Gas & Water Systems

## Propane System
- **Safety Principle (UNDER REVIEW):** The original rule was full left/right gas-electric separation. Since the electrical bay and fridge moved to the RIGHT side (2026-07 layout change), this principle is *parked* — the layout is being fixed first, then the gas routing and quick-connect positions will be refined around it (options: route gas along the left rail instead, or keep right-side pipes with vertical/distance separation from the electrical bay).
- **Front Placement:** The P6/PK6 bottle lives in a **caravan-style gas locker box** on the drawbar, flush against the front wall — lockable (bottle theft is real), fully weather/stone protected, and inspector-friendly: it is the housing every registreringsbesiktning has seen a hundred times. Low-level vents per EN 1949 (propane sinks; the box floor sits on open bearers so gas can never pool), regulator and hose inside, fixed pipe out through a floor gland to the right rail. The box is clamped to the drawbar — no holes in the beam. (Budget alternative: the open CNC cradle + bent stone guard, `cad/gas_bottle_mount.scad`.)
- **External Outlets:** Two CNC-milled niches in the trailer's right Dibond side: **front-right** (short hose around the front corner feeds a gas stove on the slide-out kitchen counter, front left) and **rear-right** (Muurikka griddle or loose outdoor kitchen at the tail). The niches ensure that the quick connects (GOK/Truma with valve) do not protrude and get knocked off during tight forest driving. Both sit low-ish — propane sinks, so they stay below the 230V inlet (front wall, right half, high) and away from cabin openings — but above wheel-spray height.
- **No Gas to the Drawers:** Propane terminates at the fixed external quick-connects — nothing flexible, and nothing routed alongside electrical cables. The rear fridge drawer holds a 12V compressor unit (works off-level, no flame, no flue — an absorption fridge would need to be level and vented per EN 1949, which is incompatible with a slide-out), and the stove connects outdoors to the front-right quick-connect. The energy chains to both drawers carry **electrical only**, which keeps the left/right gas-electric separation intact all the way.

## Water System (Centered)
- **Center of Gravity:** The 40L tank weighs nearly 45 kg full. Placed just ahead of the torsion-axle tube so consumption doesn't drastically swing the tongue weight, and **offset LEFT of the central drawbar** — the beam runs under the frame centerline (y 575-625), so a centered tank is geometrically impossible. The left offset usefully counterbalances the right-side galley mass (battery box + fridge).
- **Protection:** Suspended in a steel frame/straps under the trailer. Protected from below with a heavy-duty 3 mm aluminum tread plate (skid plate) with a 45-degree beveled leading edge. **Low-profile tank (160 mm deep) on purpose:** a 220 mm tank hung to ~336 mm ground clearance and was the trailer's lowest point; at 160 mm the skid sits at ~405 mm, roughly level with the axle tube, so wheels/axle meet obstacles first and the skid only takes glancing hits. (Alternative if this still feels exposed: move the tank inside the cabin above the floor — full protection and frost-friendlier, at the cost of cargo space and higher CG.)
- **Pipe Routing:** A 12V galley pump is mounted indoors (frost-free/protected) on rubber mounts to absorb pump noise. Externally lockable filler cap in the Dibond wall.
- **Drainage:** An absolute requirement is a low point with a drain valve that can be opened from the side of the trailer before freezing temperatures.

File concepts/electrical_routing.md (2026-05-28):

# Concept: Electrical & Network Routing (Left Side)

**Purpose:** Maximize operational reliability, personal safety, and signal integrity through rigorous separation from propane, single-point grounding, and smart exposure/encapsulation.

## Details & Structure
- **Single-Point Grounding (Star Grounding):** The chassis features a central, heavy-duty bolt/terminal. All subsystems (230V protective earth, 12V negative, and equipotential bonding) are routed here together. The purpose is to avoid stray currents and ground loops. The steel frame is connected with a 6 mm² yellow/green cable.
- **Tunnel Design in Corners:** The steel acts as an armored conduit, but at each 90-degree corner, the profiles are welded shut (or bolted tightly). Drilling with a rubber grommet is done just *before* the corners, and the flexible conduit takes a soft "shortcut" inside the double sandwich of aluminum plates.
- **Network (RF):** Coaxial cables (like LMR-200/400) are sensitive to sharp bends and crush damage. The corner passthroughs must have a carefully calculated bending radius.
- **Modular Power Station:** Designed as a standalone box. The box has large, heavy-duty Anderson connectors on the outside for in/out. It contains the 12V battery bank, DC-DC charger, MPPT, and Noco 230V charger. The box must be removable from the trailer in 1 minute for winter storage or external use at basecamp.

## Next Steps
1. Sketch out a formal electrical schematic (Single Line Diagram) for 12V and 230V.
2. Design/CNC mill the electrical niche: A recessed module in the left Dibond wall that neatly houses the 230V CEE inlet and weather-protected N-connectors for the Poynting antenna.

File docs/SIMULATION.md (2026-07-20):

# Simulating the trailer — the real firmware, no hardware

PrintTrek ships a simulator that is not a re-implementation of the rules: it
is the **actual firmware**, compiled for a stock `esp32dev` board and
executed under [Espressif's QEMU fork](https://github.com/espressif/qemu),
wired to *your* MQTT broker and therefore *your* Home Assistant. The pump
protection, lights shedding, and fridge-relay decisions you observe are made
by the same C++ that runs in the trailer.

```
┌────────────────────────── podman container ──────────────────────────┐
│                                                                      │
│  ┌───────────────────────────────┐      ┌─────────────────────────┐  │
│  │ QEMU (machine esp32)          │ SNTP │ webui.py                │  │
│  │  REAL firmware:               │─────►│  · simulated clock      │  │
│  │  sim-trailer.yaml             │ :123 │  · sensor injections    │  │
│  │  = trailer-base               │      │  · live entity view     │  │
│  │  + radio-openeth (emu eth)    │      └───────────▲─────────────┘  │
│  │  + sim-sensors (injectable)   │                  │ http :8080     │
│  │  + REAL actuators/automations │                  │                │
│  └───────────────┬───────────────┘                  │                │
└──────────────────┼──────────────────────────────────┼────────────────┘
                   │ MQTT (discovery, telemetry,      │
                   ▼        retained setpoints)     browser
            YOUR broker ──► YOUR Home Assistant
```

The simulator engine (container build, web UI, QEMU glue) lives in the
shared [esphome-skills](https://github.com/heavy-oil1462/esphome-skills)
package; the PrintTrek side is `tools/project.py` (injections, presets,
node names) and `tools/test_sim.py` (rule assertions).

## Quickstart

```bash
python3 tools/sim_container.py build                # once (~minutes)
python3 tools/sim_container.py run \
    --broker 192.168.1.10 --username printtrek --password ...
python3 tools/sim_container.py logs                 # firmware serial console
```

Open **http://localhost:8080**: sliders for every sensor, a time-of-day
control, presets ("Low battery (tier 2)", "Tank nearly empty", ...), and a
live view of everything the node publishes. The node appears in Home
Assistant via MQTT discovery as `printtrek-sim`, indistinguishable from
hardware — flip its light switch in HA and watch the entity react.

The first `run` compiles the firmware inside the container against your
broker settings; the `printtrek-sim-cache` volume makes later starts fast.
If the broker runs on the container host, use `--broker
host.containers.internal` (the entrypoint resolves it to an IP before baking
it into the firmware — QEMU's user-mode network can't see container DNS).

## How each input reaches the real firmware

| Input | Mechanism |
|---|---|
| Sensor values  | Retained MQTT topics `printtrek/<node>/sim/<key>`; `packages/sim-sensors.yaml` subscribes with the **real sensor ids** (`water_level`, `battery_voltage`, ...) so the stock automation packages run unmodified |
| Time of day | webui.py answers the firmware's SNTP queries (`sntp_server: 10.0.2.2`, re-sync every 15 s) with an offset clock — the daily pump counter resets on it |
| Setpoints & switches | Nothing special — the standard `.../command` topics (PROTOCOL.md); drive them from HA or the UI like on hardware |

Injection keys: `battery` V · `battery_current` A · `water` % ·
`temperature` degC · `humidity` % · `fridge_temp` degC. (`battery_power`
and `water_volume` are derived on-device.) Until a value is injected the
sensor has no state (NaN) and the fail-safes behave exactly as with broken
hardware: the pump refuses to run, load shedding holds its tier.

## Radio behaviour in the simulator

The node defaults to "Radio Always On", so the sim stays connected and
reacts instantly. To rehearse storage mode, press **Duty-cycled radio** (or
flip the switch in HA): an emulated NIC can't be powered down, so
`packages/radio-openeth.yaml` emulates the duty cycle at the MQTT layer —
`radio_off` publishes the retained `status: offline` (standing in for the
LWT an abrupt WiFi power-down would trigger) and disconnects; `radio_on`
reconnects. `telemetry_interval_min` is `2` in `sim-trailer.yaml`, so
windows come quickly.

## Testing "if this then that" from Home Assistant

Because the sim is a protocol-faithful node on your real broker, it is the
safe place to rehearse HA automations: point them at the `printtrek-sim`
entities, drag the battery slider to 12.3 V, and check your low-battery
alert fires; set water to 3 % and watch the pump refuse to start — driven
by the on-device rules, not HA.

## The automated version: tools/test_sim.py

The same loop, CI-style — throwaway mosquitto, web UI driven over HTTP,
assertions on the broker:

```bash
sudo -E nix develop .#sim -c python3 tools/test_sim.py
```

asserts boot/discovery, injection round-trips, direct lights control, the
low-water pump refusal, tier 1/2/3 escalation (lights shed, fridge cut),
and cascaded recovery with the fridge relay restoring itself.
Requirements: an esphome that can compile (pip fallback if the nix
platformio wrapper can't run its sandbox), `qemu-esp32` (in the `.#sim`
devshell via the `esphome-skills` flake input — kept out of the default
shell because it may build QEMU from source once), and the ability to bind
udp/123 (root/CAP_NET_BIND_SERVICE) — lwIP's SNTP port is not configurable.
Slow (a compile plus several minutes of emulated control-loop time);
deliberately not part of the default verification gate.

## Limitations

- **Not cycle-accurate**: QEMU timing is roughly wall clock, good enough for
  minute-scale control loops; don't benchmark on it.
- **GPIO goes nowhere**: relay pins drive emulated pins; observe actuators
  via their entities (which is what HA sees too).
- **Clean-disconnect offline**: see radio note above.
- **Timezone**: the UI's time slider is interpreted in `--timezone`
  (default Europe/Stockholm) — keep it equal to the firmware's `timezone`
  substitution.
- **OTA/safe-mode exist but are pointless** in a container that rebuilds
  from source each config change.

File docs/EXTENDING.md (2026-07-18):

# Extending the PrintTrek control system

The firmware is adopted by **composing packages and overriding
substitutions** — never by editing `trailer-base.yaml` or the stock
packages. If you find yourself editing core files to adapt to your hardware,
that's a design bug; open an issue.

## How composition works

Your node config (start from `esphome/example-trailer.yaml`) includes
packages and overrides their substitutions:

```yaml
substitutions:
  node_name: my-trailer
  water_adc_pin: GPIO32          # overrides the package default
  pump_max_runtime_s: "300"

packages:
  base: !include trailer-base.yaml               # always
  radio: !include packages/radio-wifi.yaml       # exactly one radio package
  i2c: !include packages/bus-i2c.yaml            # once, if any I2C sensor
  battery: !include packages/sensor-battery-shunt.yaml
  pump: !include packages/actuator-pump.yaml
  water_guard: !include packages/automation-water.yaml
  my_sensor: !include packages/sensor-my-thing.yaml   # your own
```

ESPHome merges substitutions with the **including file winning**, so package
defaults are exactly that — defaults. Values you must quote: anything used
inside a lambda as a number (`"600"`, `"12.8"`).

## The id contracts

Packages talk to each other only through entity/global ids, resolved via
substitutions so any package can be swapped for a compatible one:

| id (default) | Kind | Provided by | Consumed by |
|---|---|---|---|
| `load_shed_tier` | global int 0-3 | **base** (always 0 without the load-shedding package) | every actuator/automation package |
| `radio_on` / `radio_off` | scripts | the radio package (radio-wifi, radio-openeth) | base's radio-window scheduler |
| `net_time` | time component | base | automation-water (daily counter reset) |
| `battery_voltage` | sensor (V) | sensor-battery-shunt | automation-load-shedding (`loadshed_battery_sensor`) |
| `water_level` | sensor (%) | sensor-water-level, or water-no-sensor (constant stub — pump without a level sender) | automation-water (`water_sensor`) |
| `water_pump` | switch | actuator-pump | automation-water (`water_pump_switch`) |
| `interior_temperature` / `interior_humidity` | sensors | sensor-sht3x | HA dew-point template |
| `fridge_temperature` | sensor | sensor-fridge-ds18b20 | HA warm-fridge alert |
| `bus_a` | i2c bus | bus-i2c | all I2C sensor packages |

Swapping hardware = writing a package that provides the same id. A hall-effect
flow-based level estimate, an SHTC3 instead of the SHT3x, a smart-shunt with
a serial interface — all fine as long as the id and unit match. The
simulator is the extreme case: `packages/sim-sensors.yaml` provides all the
sensor ids from MQTT injections and `packages/radio-openeth.yaml` provides
the radio scripts for an emulated NIC, and every automation runs unchanged
(docs/SIMULATION.md).

## Where does *my* node config live?

Not in this repo — node configs are downstream consumers. Two good homes:

* **A private config repo cloned inside your PrintTrek checkout** (the repo
  gitignores `printtrek-config/`). Your config is substitutions + a package
  list with `!include ../esphome/...` paths, so it always builds against the
  checkout you have:

  ```bash
  cd PrintTrek && git clone <your-private-config-repo> printtrek-config
  esphome run printtrek-config/trailer.yaml
  ```

* **ESPHome remote packages** — no local checkout needed, pin a ref:

  ```yaml
  packages:
    printtrek:
      url: https://github.com/heavy-oil1462/PrintTrek
      ref: main            # pin a tag for production
      refresh: 1d
      files: [esphome/trailer-base.yaml, esphome/packages/radio-wifi.yaml, ...]
  ```

Every package file is standalone (no cross-`!include`s) and `!secret` always
resolves against *your* config's secrets.yaml, so both forms work unchanged.

## Radio (transport) packages

`trailer-base.yaml` never touches wifi directly. It drives the duty cycle
through two scripts that exactly one included radio package must provide:

* `radio_on` — bring the transport up
* `radio_off` — take it down (called only when "Radio Always On" is off)

`packages/radio-wifi.yaml` is the hardware implementation (wifi +
wifi.enable/disable + RSSI diagnostics); `packages/radio-openeth.yaml` the
QEMU one (MQTT-layer disconnect). A wired-ethernet node is a new radio
package, not a base edit. Keep `reboot_timeout: 0s` semantics: a node must
never reboot just because the network is absent.

## Writing a sensor package

`packages/sensor-outside-ds18b20.yaml`:

```yaml
# =============================================================================
# PrintTrek — packages/sensor-outside-ds18b20.yaml
# Outside-air DS18B20 on its own 1-wire pin.
# Substitutions:
#   outside_onewire_pin  (default GPIO5)
#   outside_update_interval  (default 60s)
# Provides: sensor id outside_temperature (degC)
# =============================================================================
substitutions:
  outside_onewire_pin: GPIO5
  outside_update_interval: 60s

one_wire:
  - platform: gpio
    id: outside_onewire_bus
    pin: ${outside_onewire_pin}

sensor:
  - platform: dallas_temp
    one_wire_id: outside_onewire_bus
    name: Outside Temperature
    id: outside_temperature
    update_interval: ${outside_update_interval}
```

Conventions (enforced in review):

1. **Header block** documenting every substitution, its default, and what
   ids the package *provides* / *requires*.
2. Substitutions for every pin, threshold, and interval. Sane defaults.
3. Short `update_interval` is fine — sampling is local and nearly free.
4. Keep entity **names** stable — object_ids derived from them feed the HA
   package, dashboard, mock, and simulator (see PROTOCOL.md).

## Writing an actuator package — safety checklist

Actuators must protect themselves **locally**; assume every automation, HA,
and the network can fail at any moment:

- [ ] Fail-safe boot state (`restore_mode: ALWAYS_OFF` for pump/lights;
      the fridge relay restores ON — cold food beats a dark boot).
- [ ] A hard runtime cap on anything that draws power while active
      (see the watchdog script pattern in `actuator-pump.yaml`).
- [ ] A local tier gate: an `interval:` that forces the actuator to its safe
      state when `id(load_shed_tier)` exceeds its tier (lights: 1, pump: 2,
      fridge: 3).
- [ ] No retained MQTT commands (`command_retain` only on setpoints — replay
      hazard, PROTOCOL.md "Retention rules").

The tier ladder: tier 1 sheds comfort loads (lights), tier 2 leaves the
fridge only, tier 3 stops everything. Gate pattern:

```yaml
interval:
  - interval: 30s
    then:
      - if:
          condition:
            lambda: 'return id(load_shed_tier) >= 1 && id(awning_led).state;'
          then:
            - switch.turn_off: awning_led
```

## Writing an automation package

Follow `automation-water.yaml` as the reference: one `interval:` control
loop, all runtime knobs as `number`/`switch` template entities with
`restore_value: true` + `command_retain: true`, hard gates first (each one
actively forces the safe state, not just skips). Treat NaN sensor reads as a
fault and choose the fail-safe branch explicitly (no pumping / hold tier).

## Hooks

`automation-load-shedding.yaml` exposes a `loadshed_tier_changed` script that
runs on every tier change. Extend it from your node config without touching
the package:

```yaml
script:
  - id: !extend loadshed_tier_changed
    then:
      - if:
          condition:
            lambda: 'return id(load_shed_tier) >= 1;'
          then:
            - switch.turn_off: awning_led
```

## Home Assistant side

New entities flow through automatically via MQTT discovery. The repo's HA
package (`homeassistant/packages/trailer.yaml`) references entity ids
explicitly — extend it (and `homeassistant/dashboards/trailer.yaml`) when
you add sensors worth alerting on.

## Before you PR

```bash
nix develop -c python3 tools/validate.py        # must be green
nix develop -c python3 tools/test_protocol.py   # if you touched MQTT semantics
nix develop -c esphome compile esphome/example-trailer.yaml  # if you touched lambdas
```

If you changed protocol semantics, update `docs/PROTOCOL.md`,
`tools/mock_device.py`, and `tools/test_protocol.py` in the same PR.

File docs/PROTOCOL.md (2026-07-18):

# PrintTrek MQTT protocol

This document is the contract between the firmware (`esphome/`), the server
stack (`server/`), Home Assistant (`homeassistant/`), and the mock device
(`tools/mock_device.py`). `tools/test_protocol.py` asserts it. If you change
semantics here, change all of them together.

## Topic tree

All topics live under `<root>/<node>` where `root` defaults to `printtrek`
(substitution `mqtt_root`) and `node` is the ESPHome `node_name`.

```
printtrek/<node>/status                                availability (LWT/birth), retained
printtrek/<node>/sensor/<object_id>/state              numeric telemetry, retained
printtrek/<node>/text_sensor/<object_id>/state         text telemetry, retained
printtrek/<node>/binary_sensor/<object_id>/state       ON/OFF, retained
printtrek/<node>/switch/<object_id>/state              ON/OFF, retained
printtrek/<node>/switch/<object_id>/command            ON/OFF        <- HA/user writes
printtrek/<node>/number/<object_id>/state              float, retained
printtrek/<node>/number/<object_id>/command            float         <- HA/user writes
printtrek/<node>/button/<object_id>/command            PRESS
```

`object_id` is the ESPHome entity name, lowercased with underscores
("Battery Voltage" -> `battery_voltage`). These ids are **load-bearing**:
the HA package, dashboard, mock device, and simulator web UI all reference
them. Rename only with a sweep across all of them.

Simulated nodes (docs/SIMULATION.md) additionally consume a
`printtrek/<node>/sim/<key>` subtree — retained raw sensor injections for
the firmware's mqtt_subscribe twins. It is an input, not telemetry, and it
exists only when `packages/sim-sensors.yaml` is included. Real nodes have no
`sim/` topics.

## Radio modes: always-on (default) vs duty-cycled storage

The trailer node ships with **"Radio Always On" = ON**: the node stays
connected and behaves like any live ESPHome device — direct switch commands
(lights, pump) take effect immediately, which is the point of running Home
Assistant here.

Switching "Radio Always On" OFF puts the node in **storage mode**: the
radio is down by default and every `telemetry_interval_min` (default 10) it
opens a **radio window**:

```
 radio_on    --> MQTT connect --> publish "online" (retained)
             --> publish full state snapshot (every entity, retained)
             --> linger radio_linger_s (default 20 s):
                   retained setpoint commands arrive and are applied
             --> radio_off
 ...keepalive (15 s) expires --> broker publishes LWT: status = "offline"
```

`radio_on`/`radio_off` come from the node's radio package: on hardware
(`packages/radio-wifi.yaml`) they are `wifi.enable`/`wifi.disable` and the
abrupt power-down makes the broker fire the LWT one keepalive later. The
simulator (`packages/radio-openeth.yaml`) disconnects cleanly instead, so it
publishes the retained `offline` itself, immediately — same observable
protocol, slightly earlier timestamp.

Consequences, all deliberate:

* `status` means **"radio up right now"**, not "device alive". In storage
  mode a healthy node is `offline` ~95% of the time.
* Load-shed tier 2 multiplies the storage-mode period (default x3); tier 3
  drops to an hourly beacon (`loadshed_tier3_beacon_min`).
* **Device health = telemetry freshness.** A node that misses even the
  hourly beacon is genuinely down. The HA package alerts when the `uptime`
  sensor (always changing) is >90 min stale.

## Availability and Home Assistant discovery

ESPHome MQTT discovery is enabled (`homeassistant/...` prefix, retained), so
HA auto-creates every entity. The firmware **disables its birth message** and
publishes `status: online` manually. This is a deliberate trick: ESPHome only
attaches per-entity availability to discovery when birth and will messages
form a matched pair, so entities in HA **never go "unavailable"** while a
storage-mode radio sleeps — they keep their retained state and stay
editable. Do not "fix" the missing birth message.

## Retention rules

| Payload | Retained? | Why |
|---|---|-----|
| `status` | yes | late subscribers must know the last state |
| all `*/state` | yes | HA must show data between radio windows |
| setpoint `*/command` (number, enable-type switches) | **yes** (`command_retain: true` in discovery) | edits made while the node sleeps are delivered at the next window |
| actuator `*/command` (pump/lights switches, buttons) | **no** | replay hazard: a retained `ON` would re-fire at every reconnect — imagine the pump starting hours after you clicked |

The asymmetry in the last two rows is a safety property, not an oversight.
With the default always-on radio it is invisible (commands land instantly
either way); in storage mode it means manual actuator control requires the
node to be online, while sleeping-safe control goes through setpoints (e.g.
`fridge_enabled`, `pump_enabled`).

Setpoints are also persisted to flash on the device (`restore_value`), so
they survive reboot and apply with no broker contact at all.

## Setpoints (retained, flash-persisted, HA-editable)

| Entity (object_id) | Type | Default | Meaning |
|---|---|---|---|
| `pump_enabled` | switch | ON | master enable for the pump relay |
| `pump_low_water_cutoff` | number, % | 5 | force pump off below this level (dry-run protection) |
| `fridge_enabled` | switch | ON | user intent for the fridge relay; relay = enabled AND tier < 3 |
| `radio_always_on` | switch | ON | live node (default) vs duty-cycled storage mode |

## Direct actuators (commands NOT retained)

| Entity (object_id) | Type | Local protection |
|---|---|---|
| `water_pump` | switch | max-runtime watchdog; refused at tier >= 2; forced off below the low-water cutoff or on sensor fault |
| `exterior_lights` | switch | auto-off watchdog (default 2 h); refused at tier >= 1 |

The fridge relay is deliberately NOT directly commandable — use
`fridge_enabled`. Its observable state is `binary_sensor/fridge_power`.

## Core telemetry (all retained)

| object_id | Unit | Source package |
|---|---|---|
| `battery_voltage` | V | sensor-battery-shunt (INA226) |
| `battery_current` | A (+ charge / - discharge) | sensor-battery-shunt |
| `battery_power` | W | sensor-battery-shunt |
| `water_level` (+ `water_level_raw_voltage`) | %, V | sensor-water-level |
| `water_volume` | L | sensor-water-level (derived) |
| `interior_temperature`, `interior_humidity` | degC, % | sensor-sht3x |
| `fridge_temperature` | degC | sensor-fridge-ds18b20 |
| `water_pump`, `exterior_lights` | ON/OFF | actuator packages |
| `fridge_power` | ON/OFF | actuator-fridge |
| `pump_used_today` | s | automation-water |
| `load_shed_tier` | 0-3 | base (numeric mirror of the global) |
| `load_shed_state` | text | automation-load-shedding |
| `wifi_rssi` | dBm | radio-wifi |
| `uptime` | s | base — freshness signal, see above |

## QoS and sessions

Everything is QoS 0 on the device side; correctness comes from retention,
not delivery guarantees — the next snapshot supersedes anything lost.

## Worked example: changing a setpoint while the node sleeps (storage mode)

1. 12:00:05 — HA user drags "Pump Low Water Cutoff" to 10. HA publishes
   `printtrek/trailer/number/pump_low_water_cutoff/command` = `10`,
   **retained**. The node is asleep; the broker stores the message.
2. 12:08:00 — node opens its radio window, connects, subscribes; broker
   delivers the retained `10`.
3. The number entity applies 10, saves it to flash, and echoes
   `.../state` = `10` (retained) — HA converges.
4. Every pump decision from this tick on uses 10, even if the broker
   burns down afterwards.

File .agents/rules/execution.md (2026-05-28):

---
trigger: always_on
---

# Execution & Behavioral Constraints

## 🛡️ Sandbox Environment Constraints (CRITICAL)
- **You are running inside an isolated NixOS Podman sandbox.** 
- You do **not** have access to the user's underlying host machine.
- You have full `root` access to this container environment, however, **do not imperatively install any tools or packages**. Rely exclusively on the tools already provided in the environment.
- You may run local servers, execute tests, and run bash scripts without worrying about breaking the user's host machine.
- **No External Network Calls**: Do NOT make outbound network requests, `curl` external APIs, or contact third-party services on your own. You must rely solely on local data and tools.
- **Strict Isolation (No SSH or Git access)**: Do NOT attempt to touch, mount, read, or configure host SSH keys, SSH agent sockets, or host Git configurations. You must remain completely contained inside this container.
- **No Rule Modifications**: You are strictly forbidden from modifying, editing, deleting, or appending to any rule files (including this one or other files in the `.agents/rules/` directory).
- Your current workspace directory (`/home/hampus/workspace/nixos` on the host) is mounted as `/workspace`. Any code changes you make here will be saved permanently on the host. 
- The CLI state is mounted to a persistent volume, so your login and internal data will persist across sessions.

## 📂 Directory Boundaries & Usage Rules
The repository is structured strictly. Adhere to the following directory rules:

### ✅ Permitted Directories (You may edit these)
- `cad/`: contains openscad files for the project.
- `containers/`: Contains declarative OCI container definitions (e.g., `homeassistant.nix`, `antigravity-sandbox.nix`).
- `software/`: Contains static configuration files for services (e.g., `configuration.yaml` for Home Assistant). 
- `scripts/`: Contains shared shell scripts.
- `docs/` and `README.md`: Documentation files.

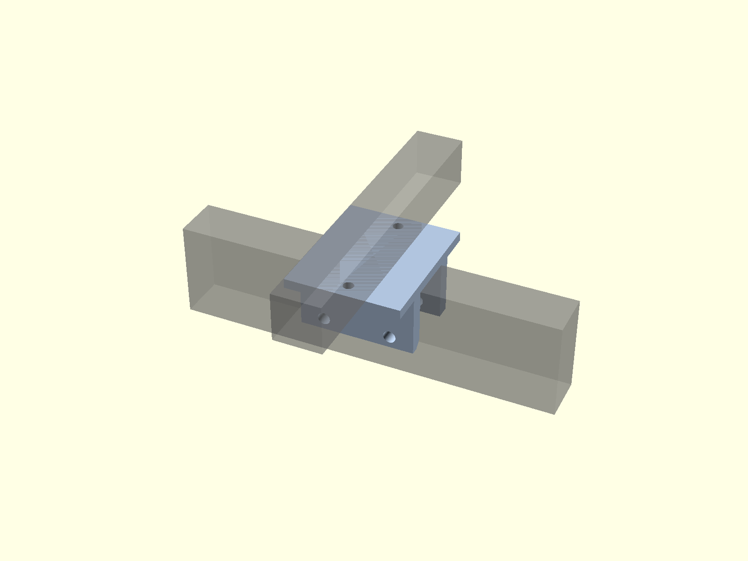
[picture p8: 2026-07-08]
drawbar_cradle.png

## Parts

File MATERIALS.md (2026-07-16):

# Material & Component List (BOM)

## Chassis & Mechanics
- **Steel Profiles:** Square steel tubes VKR 50x50x3 mm — ONE profile for the whole trailer: rails, crossbeams, AND the two V-drawbar arms (2x ~1.75 m, straight square cuts only). (Legacy single-bar alternative: drawbar in VKR 100x50x4 mm, ~2.1 m, standing on edge.)
- **Corner Plates:** Aluminum 6082-T6, 8-10 mm (for CNC milling). T-plates: 4x for the mid crossbeam (top+bottom sandwich) + 8x for the OPTIONAL floor crossbars at x=500/1500 (same CNC part, same top+bottom sandwich; omit if the floor crossbars are toggled off — they are OFF by default).
- **V-Drawbar Plates (6082-T6, 10 mm):** 2x apex plates (`cad/v_apex_plate.scad`, top+bottom sandwich over the arm tips, ~1.2 kg ea); 4x wedge spacer plates (`cad/drawbar_wedge_plate.scad`) for the angled laps at the front crossbeam and rail ends; 2x gas-box bearer plates spanning the arms.
- **Fasteners:** Through-bolts M12 in grade 8.8 or 10.9 throughout — ONE bolt size, one 13 mm hole size, one ~91 Nm torque figure for every structural joint. Plate joints use 2 bolts per arm on the tube centerline (e2 = 1.9·d0 vs the old M10 zig-zag's 1.18·d0). Lock nuts (or Nord-Lock washers) and hardened washers — with 2 bolts per arm instead of 3-4, positive locking is mandatory, not optional. (M10 remains only in non-structural mounts, e.g. the gas-box bearers.)
- **Crush Sleeves:** Internal steel sleeves for every through-bolt (precision tube, 20x3 mm for M12; 16x2.5 mm for the odd M10), cut to the inner width of the VKR profile — required to reach full bolt preload without collapsing the 3 mm tube walls.
- **Galvanic Corrosion Insulation:** Duralac anodic paste; optionally 0.5-1 mm G10/FR4 sheet as a rigid isolator. (No rubber/vinyl shims in structural joints — elastomers creep and kill bolt preload.)
- **Wheels & Axle:** Braked torsion axle (overrun brakes, e.g., Knott/AL-KO) with 6x139.7 bolt pattern + shock absorber (damper) kit + matching overrun coupling with breakaway cable.
- **Tires/Rims:** Falken Wildpeak A/T3W 265/60R18 on Ford Ranger original rims (x2 — no spare on the trailer; the Ranger's underslung spare serves both).
- **Gas Locker Box:** Caravan-style drawbar box for the P6 bottle (off-the-shelf poly, Fiamma/Thule class, or CNC-folded aluminum tread plate), with low-level ventilation per EN 1949, lockable lid, internal strap points. Mounting on the V-drawbar: bolts onto 2x 10 mm aluminum bearer plates spanning the two arms (single-bar alternative: bearers + U-straps clamped around the beam — no holes in any drawbar member either way).
- **Drawbar Joint (front crossbeam):** sleeve-clamp per V-arm crossing: 2x M12 through the crossbeam beside the arm + 2x steel spacer sleeves (~18x3 mm, 60 mm, cut ~0.5 mm short so the arm carries the preload) + 1x 10 mm 6082-T6 clamp plate (60x140) under the arm — zero holes in the arm at its peak-moment point (`check_v_joints`). Rail-end laps: 1x M12 each through rail + wedge + arm. (Legacy single-bar joint: 2x steel angle L80x80x8 S355, 120 mm, hot-dip galvanized; CNC-milled 6082-T6 cradle; or M12 square U-bolts — which fit the straight bar, but not the V's skewed crossings.)

## Electrical System & Electronics (Left Side)
- **Cable Protection:** Corrugated conduit (automotive grade).
- **Distribution Board:** IP65-rated electrical cabinet, grounding busbar for star grounding.
- **Cables:** 6 mm² yellow/green ground cable for equipotential bonding, various tinned marine/automotive cables.
- **230V Components:** Blue CEE inlet, residual current device (RCD), circuit breakers (10A/13A), IP66-rated external outlets.
- **Charging & Battery:**
  - LiFePO4 battery 200 Ah (~19 kg) with BMS + battery shunt/coulomb counter.
  - Noco battery charger (230V to 12V).
  - DC-DC charger with built-in MPPT (e.g., Victron or Renogy), 30 A.
  - Solar: 200 W rigid panel, roof-rack mounting brackets, MC4 cabling to the external solar input.
  - Heavy-duty Anderson connectors.
- **Network:** Teltonika 5G industrial router (12V), Poynting 5G/Wifi puck antenna, LMR-200/400 coaxial cables, external N-connectors.

## Propane System (Right Side)
- **Tank:** 6 kg propane cylinder (P6/PK6).
- **Piping:** Copper or steel pipes (adapted for vehicles/gas), clamps.
- **Bulkheads:** Bulkhead fittings for sheet metal/Dibond.
- **External Outlets:** GOK / Truma gas quick connects with built-in shut-off valves.

## Water System & Body
- **Water:** Food-grade 40-liter water tank (with baffles), 12V galley pump (Seaflo/Shurflo).
- **Tank Protection:** 3 mm aluminum tread plate for underbody protection (skid plate).
- **Filler:** External lockable water filler, drainage/winterization valve.
- **Structure/Walls:** 12-15 mm form plywood (floor), 3-4 mm aluminum composite / Dibond (sides).
- **Galley Modules:** TWO pairs of heavy-duty drawer slides (100-150 kg capacity, lock-in/out): one pair for the front-left kitchen side-drawer, one pair for the rear-right fridge drawer. Plywood for the mid-left storage cabinet and the mid-right electrical bay + exterior door hardware x2 (hinges, compression latches, seals). Energy chains/cable carriers (electrical only — no gas hose in the chains).
- **Appliances:** 12V compressor fridge (e.g., Dometic CFX3 or Engel MR040).

## Road Equipment (Registration Requirements)
- **Lighting:** E-marked LED trailer lighting kit (tail/brake/indicator, number-plate lamp, rear fog), triangular rear reflectors, side/front reflectors, 13-pin connector.
- **Fenders:** Mudguards sized for 265/60R18.
- **Coupling & Safety:** Type-approved coupling head, breakaway cable/safety chain, jockey wheel.

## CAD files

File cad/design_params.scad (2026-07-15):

// ============================================================
// DESIGN TOGGLES — the single source of truth.
//
// Read by ALL THREE consumers, so a value changed here flips the
// whole pipeline at once:
//   - cad/main_assembly.scad   (include <design_params.scad>)
//   - scripts/calculate_mass.py \  via scripts/design_params.py,
//   - scripts/gen_frame_fea.py  /  which parses this file
//
// One-off overrides WITHOUT editing this file:
//   - OpenSCAD:  -D floor_crossbars=true   (-D beats the include)
//   - Python:    FLOOR_CROSSBARS=true python3 scripts/...  (env var,
//                UPPERCASE of the name below)
//   - Pipeline:  the same env vars work for scripts/regen_all.sh,
//                which forwards them to the renders as -D flags.
//
// Keep this file to simple `name = value;` lines — the Python parser
// (scripts/design_params.py) only understands booleans and numbers.
// ============================================================

// OPTIONAL floor crossbars at x=500/1500 incl. their T-plate
// sandwiches (frame-neutral per FEA — they serve the formply floor
// span, lashing points, and the water-tank hanger).
floor_crossbars = false;

// Drawbar variant — DECIDED 2026-07-15: the V-drawbar (A-frame) is the
// DEFAULT design. Two straight square-cut 50x50x3 arms (same profile as
// the frame) + flat CNC apex-plate sandwich; combined-case SF 3.0 vs
// 1.8 for the single bar, lateral loads go axial (check_v_drawbar and
// check_v_joints in scripts/beam_check.py). false = the legacy single
// central VKR 100x50x4 bar, kept fully modeled as the alternative.
v_drawbar = true;

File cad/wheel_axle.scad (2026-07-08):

/*
 * Offroad Adventure Trailer - Braked Torsion Axle + Wheels (visual mockup)
 *
 * Braked torsion axle (Knott/AL-KO style), 6x139.7 hubs, trailing arms,
 * and 265/60R18 Falken Wildpeak on Ford Ranger rims.
 *
 * Track width matches the Ford Ranger (1560 mm center-to-center) so the
 * spare wheel is shared and the trailer follows the car's ruts. This is
 * only possible because the frame was narrowed to 1200 mm:
 * tire-to-body clearance = (track - tire_w)/2 - frame_width/2
 *                        = (1560 - 265)/2 - 600 = 47.5 mm.
 */

tube_w = 50;
frame_width = 1200;
frame_length = 2000;

tire_dia = 775;          // 265/60R18: 18*25.4 + 2*0.6*265
tire_w   = 265;
rim_dia  = 457;          // 18 inch
track = 1560;            // Ford Ranger track, center-to-center

axle_tube = 80;          // torsion axle square tube
axle_z = -100;           // axle tube center below frame underside
trail = 90;              // trailing arm: hub sits this far behind the tube
hub_z = -190;            // wheel center below frame underside

$fn = 60;

module wheel() {
    rotate([90, 0, 0]) {
        // Tire
        color([0.13, 0.13, 0.13])
        difference() {
            cylinder(d=tire_dia, h=tire_w, center=true);
            for (s = [-1, 1])
                translate([0, 0, s * tire_w/2])
                    cylinder(d=rim_dia + 40, h=70, center=true);
        }
        // Rim + hub
        color("lightgray") cylinder(d=rim_dia, h=tire_w - 90, center=true);
        color("dimgray")   cylinder(d=150, h=tire_w - 40, center=true);
    }
}

// NOTE: axle_x is the position of the axle TUBE. The trailing arms put
// the hubs (= wheel centers = ground contact) `trail` = 90 mm further
// back. To land the WHEELS on the intended wheel line (AXLE_X in
// scripts/calculate_mass.py), pass wheel_line_x - trail — the assembly
// does. When ordering the real axle, specify the HUB line, not the tube.
module torsion_axle(axle_x = frame_length * 0.6 - trail) {
    y_hub_l = frame_width/2 - track/2;
    y_hub_r = frame_width/2 + track/2;

    // Axle tube between the trailing arms
    color("dimgray")
        translate([axle_x - axle_tube/2, y_hub_l + 60, axle_z - axle_tube/2])
            cube([axle_tube, track - 120, axle_tube]);

    // Mounting brackets up to the frame rails
    color("gray")
        for (y = [0, frame_width - tube_w])
            translate([axle_x - 70, y, axle_z - axle_tube/2])
                cube([140, tube_w, -axle_z + axle_tube/2]);

    // Trailing arms + wheels
    for (y = [y_hub_l, y_hub_r]) {
        color("dimgray")
            hull() {
                translate([axle_x, y, axle_z]) cube([axle_tube, 70, axle_tube], center=true);
                translate([axle_x + trail, y, hub_z]) cube([70, 60, 70], center=true);
            }
        translate([axle_x + trail, y, hub_z]) wheel();
    }
}

// Renders if the file is opened standalone
torsion_axle();

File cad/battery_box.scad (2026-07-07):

// Battery Compartment Layout

// --- Parameters ---
// Box dimensions (Internal)
box_w = 500;
box_h = 400;
box_d = 250;
box_thickness = 2;

// Battery dimensions (e.g., typical 12V 100Ah LiFePO4)
batt_w = 330;
batt_d = 170;
batt_h = 220;

// Inverter dimensions (e.g., 1000W)
inv_w = 250;
inv_h = 150;
inv_d = 100;

// Charger dimensions (e.g., 15A AC-DC)
charger_w = 150;
charger_h = 100;
charger_d = 60;

// MPPT Solar Controller dimensions (e.g., Victron SmartSolar 75/15)
mppt_w = 100;
mppt_h = 113;
mppt_d = 40;

// Safety components dimensions
din_rail_w = 100;
din_rail_h = 35;
din_rail_d = 7.5;
rcbo_w = 36; // 2-module wide RCBO
rcbo_h = 85;
rcbo_d = 70;
dc_breaker_w = 50;
dc_breaker_h = 80;
dc_breaker_d = 40;

// --- Modules ---

module enclosure() {
    // Metal electrical box
    difference() {
        // Outer dimensions
        color("SlateGray", 0.3)
        cube([box_w + box_thickness*2, box_d + box_thickness*2, box_h + box_thickness*2], center=true);
        
        // Inner dimensions (hollow out)
        cube([box_w, box_d, box_h], center=true);
        
        // Front door opening
        translate([0, box_d/2, 0])
        cube([box_w, box_thickness*3, box_h], center=true);
    }
}

module handles() {
    // Simple side handles for portability
    handle_w = 20;
    handle_h = 100;
    handle_d = 40;
    
    color("Silver") {
        // Left handle
        translate([-(box_w/2 + handle_d/2 + box_thickness), 0, 0])
        difference() {
            cube([handle_d, handle_w, handle_h], center=true);
            cube([handle_d - 10, handle_w + 2, handle_h - 20], center=true);
        }
        
        // Right handle
        translate([(box_w/2 + handle_d/2 + box_thickness), 0, 0])
        difference() {
            cube([handle_d, handle_w, handle_h], center=true);
            cube([handle_d - 10, handle_w + 2, handle_h - 20], center=true);
        }
    }
}

module external_connectors() {
    // 230V CEE Inlet (Blue, 3-pin)
    color("Blue")
    translate([-(box_w/2 + box_thickness + 10), -box_d/4, box_h/4])
    rotate([0, 90, 0])
    cylinder(d=60, h=20, $fn=32, center=true);
    
    // 2x 230V Outlets (Schuko/Waterproof)
    color("LightGray")
    translate([box_w/2 + box_thickness + 10, -box_d/4 + 40, box_h/4 + 30])
    rotate([0, 90, 0])
    cylinder(d=50, h=20, $fn=32, center=true);
    
    color("LightGray")
    translate([box_w/2 + box_thickness + 10, -box_d/4 - 40, box_h/4 + 30])
    rotate([0, 90, 0])
    cylinder(d=50, h=20, $fn=32, center=true);
    
    // 1x 12V Outlet (Cigarette lighter style or similar)
    color("Black")
    translate([box_w/2 + box_thickness + 10, -box_d/4, box_h/4 - 40])
    rotate([0, 90, 0])
    cylinder(d=30, h=20, $fn=32, center=true);
    
    // Solar Input Connector (XT60 or small Anderson)
    color("Yellow")
    translate([box_w/2 + box_thickness + 10, -box_d/4, box_h/4 - 80])
    rotate([0, 90, 0])
    cube([15, 25, 20], center=true);
    
    // Main DC Connector to Trailer (Anderson style SB175)
    color("Red")
    translate([0, box_d/2 + box_thickness + 10, -box_h/2 + 40])
    rotate([90, 0, 0])
    cube([60, 20, 80], center=true);
}

module battery() {
    // LiFePO4 Battery
    color("DarkSlateGray")
    cube([batt_w, batt_d, batt_h], center=true);
    
    // Terminals
    color("Silver") {
        translate([-batt_w/2 + 30, 0, batt_h/2 + 10]) cylinder(d=15, h=20, $fn=16, center=true);
        translate([batt_w/2 - 30, 0, batt_h/2 + 10]) cylinder(d=15, h=20, $fn=16, center=true);
    }
}

module inverter() {
    color("DodgerBlue")
    cube([inv_w, inv_d, inv_h], center=true);
}

module charger() {
    color("LimeGreen")
    cube([charger_w, charger_d, charger_h], center=true);
}

module mppt() {
    color("DarkTurquoise")
    cube([mppt_w, mppt_d, mppt_h], center=true);
}

module safety_components() {
    // DIN Rail
    color("Silver")
    translate([0, 0, -rcbo_d/2 + din_rail_d/2])
    cube([din_rail_w, din_rail_h, din_rail_d], center=true);
    
    // 230V RCBO (Ground Fault + MCB)
    color("White")
    translate([-20, 0, 0])
    cube([rcbo_w, rcbo_h, rcbo_d], center=true);
    
    // 12V DC Resettable Breaker
    color("Black")
    translate([30, 0, -rcbo_d/2 + dc_breaker_d/2])
    cube([dc_breaker_w, dc_breaker_h, dc_breaker_d], center=true);
}

// --- Main Assembly ---
// Wrapped in a module so main_assembly.scad can place the whole box.
// Origin = center of the enclosure.
module battery_box() {
    enclosure();
    handles();
    external_connectors();

    // Place Battery at the bottom
    translate([0, 0, -box_h/2 + batt_h/2])
    battery();

    // Place Inverter on the back wall, above battery
    translate([-box_w/4 + 20, -box_d/2 + inv_d/2, box_h/2 - inv_h/2 - 20])
    inverter();

    // Place Charger on the back wall, above battery, next to inverter
    translate([box_w/4 + 20, -box_d/2 + charger_d/2, box_h/2 - charger_h/2 - 20])
    charger();

    // Place MPPT Solar Controller on a side wall
    translate([box_w/2 - mppt_d/2, -box_d/4, box_h/2 - mppt_h/2 - 40])
    rotate([0, 0, 90])
    mppt();

    // Place Safety Components (Breakers) near the top or on a side wall
    translate([0, -box_d/2 + rcbo_d/2, box_h/2 - rcbo_h/2 - 120])
    rotate([90, 0, 0])
    safety_components();
}

// Renders if the file is opened standalone
battery_box();

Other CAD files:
cad/cabin.scad
cad/corner_plate.scad
cad/drawbar_angle_joint.scad
cad/drawbar_cradle.scad
cad/drawbar_wedge_plate.scad
cad/drill_guide.scad
cad/electrical_niche.scad
cad/fasteners.scad
cad/fender.scad
cad/frame.scad
cad/gas_bottle_mount.scad
cad/gas_box.scad
cad/kitchen_drawer.scad
cad/main_assembly.scad
cad/road_equipment.scad
cad/t_plate.scad
cad/v_apex_plate.scad
cad/water_tank.scad

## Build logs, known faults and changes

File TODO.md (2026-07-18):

# To-Do List: Offroad Adventure Trailer

## Phase 1: Concept & CAD Design
- [ ] Measure the Ford Ranger to determine optimal track width and drawbar height.
- [ ] Maintain the weight & tongue-load budget (`scripts/calculate_mass.py`) — decides braked vs. unbraked axle and axle position.
- [ ] Research registration requirements (registreringsbesiktning): lighting, reflectors, fenders, coupling approval. Contact inspection body early.
- [x] CAD model the base frame (VKR profiles) and define bolt patterns for the corners.
- [x] Design the drawbar attachment. (DECIDED: single central VKR 100x50x4 beam; front crossbeam = angle-bracket clamp 2x L80x80x8 with no holes in the beam flanges (`cad/drawbar_angle_joint.scad`), mid crossmember = M12 through-bolt + 10 mm spacer; the beam ends ahead of the axle tube. `cad/drawbar_wedge_plate.scad`/`drawbar_cradle.scad` kept as alternatives.)
- [x] Add fenders, lighting positions, and jockey wheel to the CAD model (`cad/fender.scad`, `cad/road_equipment.scad`, `cad/wheel_axle.scad`).
- [x] **Resolve the track width conflict:** RESOLVED by narrowing the frame to 1200 mm — the 1560 mm Ranger track now fits with 47.5 mm tire-to-body clearance (see `cad/wheel_axle.scad`). Verify against the real car in the "Measure the Ford Ranger" task above.
- [ ] Prototype and physically test ONE bolted corner joint (crush sleeves, torque retention after vibration, Duralac interface) before committing to the full frame.
- [x] Design 3D printed drill guides to ensure accurate hole placement on the steel beams (`cad/drill_guide.scad`).
- [ ] Create a simplified geometry version (non-CNC) for builders without access to a CNC router.
- [x] Set up structural-calculation tooling: `scripts/beam_check.py` (RHS bending, bolt groups, safety factors) + CalculiX FEA in `fea/` (validated drawbar model). See `.claude/skills/structural-calc/`.
- [ ] CAD design and simulate the corner reinforcements ("double sandwich") in 8-10 mm aluminum. (Modeled — corner-plate FEA remains; candidate list in `fea/README.md`.)
- [ ] Design CNC-milled niches for external electrical and gas outlets. (Electrical niche done — gas-side niches remain.)
- [ ] Design mount/cradle for propane tank on the drawbar (including stone protection). (Cradle done — stone-guard tread plate remains.)
- [ ] Develop layouts for the electrical cabinet and network components (star ground, IP65 box).
- [ ] Design the water tank placement and mounting (tank + skid modeled in `cad/water_tank.scad`, but REMOVED from the assembly for now — the underslung mount must clear the central drawbar and axle tube; placeholder mass at x=780 in the tongue budget).
- [x] CAD model the kitchen drawer with space for the 12V compressor fridge and an electrical-only cable chain (`cad/kitchen_drawer.scad`).

## Phase 2: Material Sourcing & Purchasing
- [ ] Order steel (VKR 50x50x3), through-bolts (M12 in 8.8/10.9 — one size frame-wide), and 20x3 precision tube for crush sleeves.
- [ ] Buy 6082-T6 aluminum plates for corners and framework for CNC milling (PrintNC).
- [ ] Purchase braked torsion axle (overrun brakes, bolt pattern 6x139.7) with damper kit and matching overrun coupling, and Falken Wildpeak A/T3W 265/60R18 (with original rims).
- [ ] Order road equipment: E-marked lighting kit, reflectors, fenders, type-approved coupling, jockey wheel, breakaway cable.
- [ ] Order electrical components: IP65 cabinet, Circuit Breakers/RCD, Noco charger, DC-DC MPPT (30 A), Anderson connectors, 200 Ah LiFePO4 battery + shunt.
- [ ] Order solar: 200 W rigid panel + roof-rack brackets + MC4 cabling (see `scripts/calculate_energy.py` for why).
- [ ] Order network gear: Teltonika 5G, Poynting puck antenna, LMR coaxial cables.
- [ ] Purchase gas and water systems: 40L tank, 12V galley pump, GOK/Truma quick connects.
- [ ] Materials for body: Formply (12-15 mm), Dibond (3-4 mm), heavy-duty drawer slides.
- [ ] Consumables: Corrugated conduits, marine grease/Duralac, insulation, cable glands.

## Phase 3: Chassis Build & Mechanics
- [ ] Cut and drill the steel frame (VKR) — 13 mm holes for M12 (all plate bolts on the tube centerline).
- [ ] Cut and fit internal crush sleeves for all through-bolts.
- [ ] CNC mill the aluminum corner plates and drawbar wedge/spacer plates.
- [ ] Dry fit the entire frame with bolted joints for fitment check.
- [ ] Disassemble and send the steel frame for hot-dip galvanizing.
- [ ] Ream all bolt holes clean after galvanizing.
- [ ] Apply Duralac (and G10/FR4 isolators if used) between steel and aluminum — no rubber/vinyl in the joints.
- [ ] Final assembly of the chassis and torque the bolts to spec (crush sleeves in place).
- [ ] Mount axle, dampers, brakes, wheels, and fenders.
- [ ] Schedule re-torque of all structural bolts after the first ~500 km.

## Phase 4: Electrical & Gas Installation
- [ ] Route corrugated conduit and pull electrical/network cables (left side) before fully closing.
- [ ] Install IP65 electrical cabinet and establish star ground (equipotential bonding 6 mm²).
- [ ] Build the standalone battery module (Power Station) with DC-DC/MPPT and Anderson connections.
- [ ] Mount Teltonika router, Poynting antenna, and CNC mill the recessed connection panel.
- [ ] Bench-test the ESP32 controller (esphome/example-trailer.yaml) with the relays, INA226 shunt, and tank sender before installation; calibrate the sender per docs/HARDWARE.md.
- [ ] Set up the trailer Raspberry Pi server as a nix config (Home Assistant, Grafana, Loki, Prometheus) — the repo's server/ compose stack is dev-only.
- [ ] Route propane pipes on the right side and mount CNC-milled niches with external quick connects.
- [ ] Leak test the propane system.

## Phase 5: Body, Water System & Interior
- [ ] Build and mount the floor (formply).
- [ ] Mount framework for sides and clad with Dibond sheets.
- [ ] Mount and protect the water tank (with skid plate) and install 12V pump + lines.
- [ ] Mount heavy-duty drawer slides and build kitchen drawer for the 12V compressor fridge.
- [ ] Install cable chain (energy chain) for flexible transfer of electricity to the kitchen drawer (gas stays on fixed pipes to the external quick-connects).
- [ ] Mount lighting, reflectors, and number plate; verify with 13-pin tester.
- [ ] Test run and commission all systems (water, cooling, heating, electricity).
- [ ] Book and pass registreringsbesiktning.

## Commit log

2026-05-21 Docs: Add 3D printed drill guides and non-CNC alternatives
2026-05-28 Added main assembly png
2026-07-08 Add structural-calc tooling, low-profile water tank, README design snapshots
    - scripts/beam_check.py: zero-dependency hand-calcs (RHS section library,
    drawbar vertical/lateral/combined load cases, side rail, bolt group)
    - fea/: CalculiX beam model of the drawbar, validated against the hand
    calc (deflection exact, root stress within 6%); run via scripts/run_ccx.sh
    - .claude/skills/structural-calc: skill documenting both tiers
    - cad/water_tank.scad: low-profile 160 mm tank so the skid plate sits
    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
    [frame.scad, main_assembly.scad, water_tank.scad]
2026-07-08 FEA renders + host pipeline, drawbar cradle concept, galley layout rework
    Structural analysis:
    - scripts/run_fea.sh: portable pipeline (finds ccx via PATH/nix, solves
    all fea/*.inp, renders PNGs); scripts/plot_fea.py renders .frd results
    as deformed shape + von Mises (pure numpy/matplotlib)
    - fea/corner_plate_bending.inp: NEW aluminum 6082-T6 corner-plate model
    (validated: 106 vs 113 MPa hand calc) - materials now per part:
    S355 steel beams, 6082-T6 aluminum plates
    - beam_check.py check_joint_hole: the fatigue-governing detail is the
    bolt hole at the front crossbeam lap (margin 1.3x vs 3-4x elsewhere)
    - cad/drawbar_cradle.scad: milled clamp-cradle that eliminates that hole
    (verti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
    [cabin.scad, drawbar_cradle.scad, kitchen_drawer.scad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]
2026-07-08 Whole-chassis FEA + angle-bracket joint alternative
    - scripts/gen_frame_fea.py: global beam model of the entire load-bearing
    structure (rails, crossbeams, drawbar, lap links). LC 3g deck load:
    rails 86 / crossbeams 87 / drawbar 36 MPa - SF >= 4 on all real
    members. LC diagonal racking (30 mm): 64/60 MPa - torsionally soft
    ladder frame, as intended. Verified: one-wheel-up with a ball coupling
    is a stress-free rigid roll (ball transmits no roll moment).
    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
    [drawbar_angle_joint.scad]
2026-07-08 Global FEA with angle-bracket lap + whole-chassis renders in README
    - gen_frame_fea.py: front lap now modeled as the L80x80x8 angle pair
    (legs lumped to a 120x16 connector), axle lap as the bolted spacer
    joint. Global max drops 210 -> 92 MPa (the old spike was the
    idealized link, not a real part); angles see 25 MPa in the vertical
    case - their governing case stays the lateral couple (SF 3.4).
    - README: whole-chassis stress renders (3g + diagonal racking) added
    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
2026-07-08 Angle joint in main assembly; fix axle/wheel alignment + tank collisions
    - main_assembly: drawbar_angle_joint() module at the front crossbeam
    (DECIDED - no holes in the beam flanges there); axle crossbeam keeps
    M12 through-bolt + spacer (moment ~zero, positive location). Spare
    wheel mocked on the tailgate left half.
    - Axle fix: torsion_axle() places the TUBE; hubs sit trail=90 mm back.
    Assembly now passes axle_x - trail so the WHEELS land on the axle
    crossbeam and on AXLE_X in the mass budget (they were 90 mm off).
    - Water tank: was impaled by the central drawbar and overlapped the
    axle tube - moved ahead of the tube and offset left of the beam
    (20 mm gap); the offset counterba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
    [drawbar_angle_joint.scad, main_assembly.scad, water_tank.scad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]
2026-07-08 Single mid crossbeam; drawbar clears the axle tube; English comments
    - Drawbar/axle collision fix: the beam ran to x=1250, straight through
    the torsion-axle tube (x 1070-1150, same depth). Beam shortened to
    2020 mm (ends x=1020) with its rear lap at a mid crossbeam.
    - Frame simplification (one middle beam instead of two): the axle
    crossbeam is deleted - the bolted axle tube ties the rails via its
    brackets - and the mid crossbeam (x 950-1000) takes the drawbar's
    rear M12 through-bolt. T-plates move to it. Lap couple base 0.95 m
    (angle joint SF 3.0). Cut list: 3x 1100 crossbeams, -5 kg.
    - Global FEA regenerated (supports now on the rails at the axle
    brackets): rails 130 MPa / SF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
    [cabin.scad, electrical_niche.scad, frame.scad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]
2026-07-08 Remove water tank from assembly - mounting to be reworked
    Tank + skid design kept in cad/water_tank.scad; mass stays as an
    explicit placeholder (x=780) in the tongue budget so it remains honest.
    Constraints for the future mount recorded in main_assembly.scad: must
    clear the central drawbar (y 575-625) and the axle tube (x 1070-1150).
    SPECS/TODO/README annotated; assembly render regenerated.
    [main_assembly.scad]
2026-07-08 Gas locker box, no trailer spare, fridge-only rear hatch
    - cad/gas_box.scad: caravan-style lockable gas locker on the drawbar,
    flush with the front wall - EN 1949 low-level vents, regulator
    inside, clamped to the beam (no holes in the drawbar). Replaces the
    open cradle + stone guard (kept as budget alternative).
    - Spare wheel removed from the trailer: the wheel spec matches the
    Ranger exactly, so the car's underslung spare serves both.
    - Rebalance: water-tank placeholder moved BEHIND the axle (x~1400,
    centered - freed by the spare removal, no drawbar there). Tongue
    58.5 kg (9.8%) full / 62.4 kg (11.3%) water empty; calculate_mass.py
    now reports both states and allows up to 12%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
    [cabin.scad, gas_box.scad, main_assembly.scad]
2026-07-09 Optional floor crossbars with T-plate joints; regen/verify pipeline
    - Two floor crossbars (x=500/1500) now bolt to the rails through bottom
    T-plates (same CNC part as the mid-crossbeam plates) — they were
    floating tubes with no joint. Bottom-only: FEA shows the bars are
    frame-neutral, the formply floor closes the joint from above.
    - Whole package behind ONE toggle, mirrored in three places:
    floor_crossbars (main_assembly.scad, also -D-able) and
    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
    [frame.scad, main_assembly.scad]
2026-07-15 V-drawbar (A-frame) is the default design; single-source design params
    - V-drawbar: two straight square-cut VKR 50x50x3 arms (same profile as
    the frame), flat CNC apex-plate sandwich (v_apex_plate.scad), 40 mm
    tip gap for cut tolerance, wedge-plate laps. Combined-case SF 3.0 vs
    1.8 for the single bar; lateral loads go axial. Single central bar
    kept fully modeled behind v_drawbar=false.
    - Joints: check_v_joints in beam_check.py — M12 8.8 full preload
    (47 kN, crush sleeves), friction-grip SF >= 3.9 at mu=0.2; fatigue
    drove the front-crossbeam lap to a square U-bolt CLAMP (no flange
    holes at peak arm moment).
    - FEA: gen_frame_fea.py builds real V geometry (arms share the apex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
    [design_params.scad, frame.scad, gas_box.scad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]
2026-07-15 Buildable V-drawbar joints, visible fasteners, narrower V, clamp redesign
    - Fastener display hardware (cad/fasteners.scad): every plate hole in
    the assembly shows its M10/M12 through-bolt + washers + nut; sleeve
    clamps at the V crossings. Round hardware at $fn=32, hex heads/nuts
    6-sided by design.
    - Front-crossbeam crossings: square U-bolts REJECTED by geometry (at
    the ~72 deg skew their legs land on the crossbeam's edges) — replaced
    with a sleeve-clamp: 2x M12 through the crossbeam 45 mm beside the
    arm, 60 mm spacer sleeves, 10 mm clamp plate under the arm. Zero
    holes in the arm at its peak-moment point.
    - Rail-end laps: single M12 each (the shallow overlap parallelogram
    o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
    [drawbar_wedge_plate.scad, fasteners.scad, frame.scad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]
2026-07-16 Plate joints: 2x M12 on tube centerline replaces 3x M10 zig-zag
    The zig-zag's +/-12 mm offset left e2 = 1.18*d0 on the 50 mm face — at
    the EN 1993-1-8 floor, with hole edges 7.5 mm from the tube corner
    radius. The joints are friction-grip and never capacity-limited
    (demand ~5 kN vs 37.8 kN slip per 2-bolt arm), so fewer, larger,
    centered bolts win on every axis: e2 = 1.9*d0, half the holes to
    drill/ream/sleeve, one bolt standard frame-wide (M12 8.8, 13 mm holes,
    20x3 sleeves, 91 Nm).
    - corner_plate: 2 per arm at 80/170 + corner bolt (5 holes, was 7)
    - t_plate rect: 2 through rail + 2 through crossbeam (4, was 12);
    drop the y=+/-45 "side clamp" rows — they passed beside the beam
    thro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
    [corner_plate.scad, drawbar_wedge_plate.scad, drill_guide.scad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]
2026-07-18 Replace custom control software with ESPHome + Home Assistant
    The Arduino CAN firmware, Go backend, and web dashboard are gone. The
    trailer is now controlled by one ESP32 running ESPHome over MQTT with
    Home Assistant as the UI, plus the tooling to develop and verify it all
    without hardware.
    Firmware (esphome/): composable base + packages. The node is radio
    always-on by default for direct HA control of pump, lights, and fridge;
    a duty-cycled storage mode with retained setpoints sits underneath.
    Safety logic runs locally: tiered battery load shedding (lights, pump,
    fridge last), pump dry-run cutoff and runtime watchdog, lights auto-off,
    fridge relay with automatic post-shed recovery.
    Home As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
2026-07-19 README: lead with description, goals, and features
    The readme opened with the chassis render and a dense structural-analysis
    section, so a first-time reader hit FEA stress tables before learning what
    the project is. Move the project description, Project Goals, and Key
    Features to the top; the chassis image and its caption now sit directly
    above Structural Analysis where the engineering detail starts.
    Also state up front that the bolted frame exists so the trailer can be
    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
2026-07-20 Migrate control-system tooling to the shared esphome-skills package
    The tooling engine (validation framework and generic checks, sim
    container + web UI + QEMU glue + test harness, mock device plumbing,
    protocol test harness, server stack management, devshell construction)
    now comes from the esphome-skills flake input. This repo keeps only its
    own substance: tools/project.py (names, injections, presets), check
    selection incl. the HA compose-mount list, the trailer mock physics,
    the rule test scenario, and the MQTT+HA smoke test.
    sim/ and tools/_lib.py are deleted; the sim image is now built from a
    staged context (repo esphome/ without secrets.yaml + the package's sim
    runtime), which also fix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
2026-07-21 Enable CI: three path-filtered workflows
    validate.yml runs the software gate and the MQTT protocol test on
    every change from pip; design.yml runs the full
    scripts/verify_design.sh (apt CalculiX and mosquitto, OpenSCAD
    snapshot AppImage under xvfb) on design-side paths; firmware.yml
    compiles both node configs with the platformio and esphome build
    trees cached. No OpenSCAD version recording is needed: the drift gate
    compares FEA decks, which gen_frame_fea.py produces without OpenSCAD.
